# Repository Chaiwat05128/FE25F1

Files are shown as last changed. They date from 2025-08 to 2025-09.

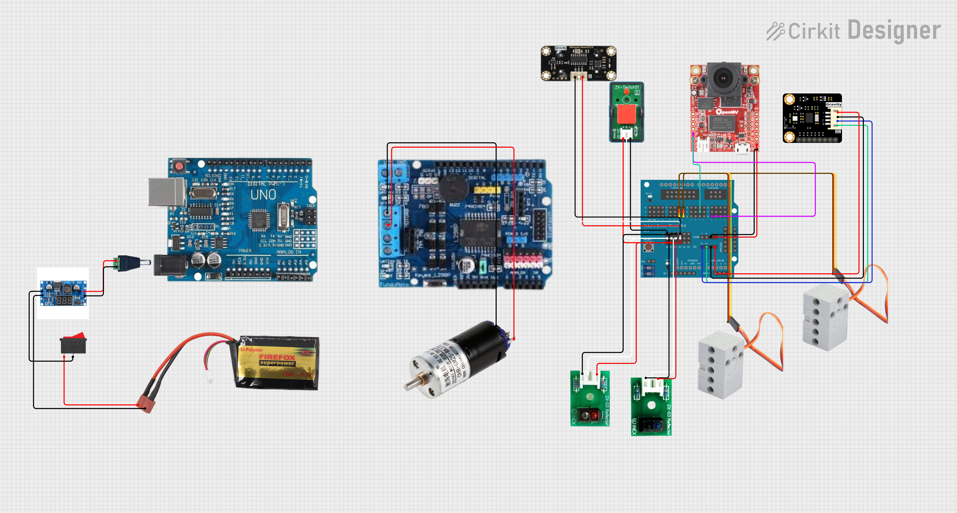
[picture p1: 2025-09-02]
Diagram/circuit_image (3).png

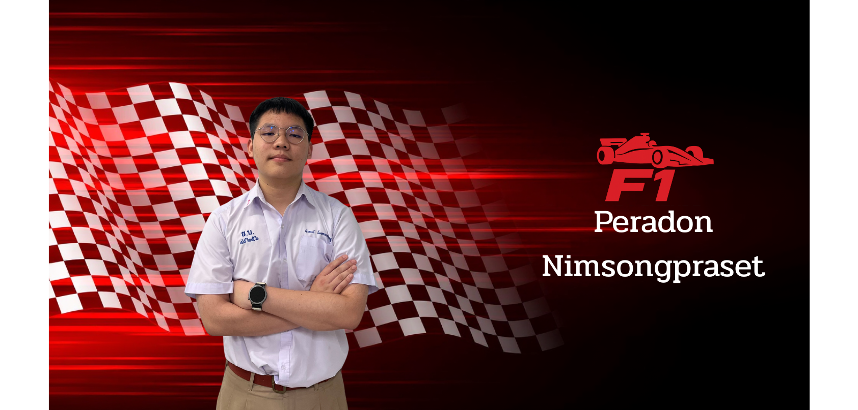
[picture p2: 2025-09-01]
Team Photo/-.zip_-_4.png

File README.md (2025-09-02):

# **🏎️Team F1 – WRO Future Engineers 2025🏁**
</p>
</p>
<br>
<p align="center">
  Team F1 logo
</p>

---

## Table of Contents
- [About Team 👥](#about-team-)
- [Project Overview 🧠](#project-overview-)
- [Timeline 🗓️](#timeline-%EF%B8%8F)
- [Robot Design](#robot-design)
  - [🖥️ Design Software](#%EF%B8%8F-design-software)
  - [🛠️ Hardware Design](#%EF%B8%8F-hardware-design)
    - [Bambu Lab X1C 3D Printer](#bambu-lab-x1c-3d-printer)
    - [Filament](#filament)
      - [ABS](#abs)
      - [PLA](#pla)
    - [Servo Bracket](#servo-bracket)
    - [Drive Bearing 1 & 2](#drive-baring-1--2)
    - [Bearing Spacer 1 & 2](#baring-spacer-1--2)
    - [Gear System](#gear)
- [Steering Mechanic Part](#steering-mechanic-part)
  - [⚙️ Geek Servo 360](#%EF%B8%8F-geek-servo-360)
- [🚗 Drive and Power Train](#-drive-and-power-train)
  - [Chihai Motor 25-370K](#chihai-motor-25-370k)
  - [LEGO Technic Differential Gear](#lego-technic-differential-gear)
  - [LEGO 8pc Technic Wheel and Tire Set](#lego-8pc-technic-wheel-and-tire-set-mindstorms-nxtev3-tyre)
  - [Lego Black Tire 49.5x20 and Light Bluish Gray Wheel](#lego-black-tire-495x20-x4-and-light-bluish-gray-wheel-304mm-x-20mm-x4)
- [Energy Management and Inspection](#energy-management-and-inspection)
  - [Gravity: URM09 Ultrasonic Distance Sensor](#gravity-urm09-ultrasonic-distance-sensor)
  - [ZX-03 Reflective Infrared Sensor Module](#zx-03-reflective-infrared-sensor-module)
  - [OpenMV Cam H7](#openmv-cam-h7)
  - [SEN 0253](#sen-0253)
- [Controller](#controller)
  - [Major Controller](#major-contoller)
    - [UNO R3](#uno-r3)
  - [Expansion Board](#expansion-board)
    - [L298P DC Motor Drive Shield](#l298p-dc-motor-drive-shield)
    - [Uno R3 Sensor Shield V5.0 for Arduino](#uno-r3-sensor-shield-v50-for-arduino)
- [Power Management](#power-managment)
  - [FIREFOX Li-Polymer BATTERY 20C 1300mAh/11.1V](#firefox-li-polymer-batterry-20c-1300mah111v)
  - [On/Off Switch](#onoff-switch--spst-onoff-switch-2-pin-rocker-switch-dc-125250v)
  - [Step-down: HW-360 V6.0](#step-down--hw-360-v60)
  - [ZX-Switch01](#zx-switch01)
- [WRO Future Engineers 2025 - Robot Components & Budget](wro-future-engineers-2025---robot-components--budget)
- [Programming](#programing)
  - [🚗 Future Engineer 2025 - Self-Driving Car Robot](#-future-engineer-2025---self-driving-car-robot)
  - [🎯 Mission Overview](#-mission-overview)
  - [🏗️ System Architecture](#%EF%B8%8F-system-architecture)
    - [Core Navigation Algorithm](#core-navigation-algorithm)
  - [🔧 Hardware Components](#-hardware-components)
    - [📋 Component List](#-component-list)
    - [⚙️ Pin Configuration](#%EF%B8%8F-pin-configuration)
  - [🎨 Line Detection Logic](#-line-detection-logic)
    - [🔴 Red Line → Turn Right](#-red-line--turn-right)
    - [🔵 Blue Line → Turn Left](#-blue-line--turn-left)
    - [🎯 Turn Execution Sequence](#-turn-execution-sequence)
  - [📐 Wall Following System](#-wall-following-system)
    - [🎛️ PID Controller Setup](#%EF%B8%8F-pid-controller-setup)
    - [📏 Distance Calculation](#-distance-calculation)
    - [🎯 Why Servo Tracks Compass Heading](#-why-servo-tracks-compass-heading)
  - [🚧 Obstacle Avoidance System](#-obstacle-avoidance-system)
    - [📷 Camera-Based Block Detection](#-camera-based-block-detection)
    - [🤝 Steering Blend Algorithm](#-steering-blend-algorithm)
  - [🎮 Control Flow States](#-control-flow-states)
    - [🔄 Robot Operation Modes](#-robot-operation-modes)
    - [🎛️ Variable Synchronization](#%EF%B8%8F-variable-synchronization)
  - [🔬 Mathematical Functions](#-mathematical-functions)
    - [🧮 Angle Wrapping](#-angle-wrapping)
    - [🎯 Motor Speed Control](#-motor-speed-control)
  - [📊 Performance Characteristics](#-performance-characteristics)
    - [⏱️ Timing Parameters](#%EF%B8%8F-timing-parameters)
    - [🎚️ Control Parameters](#%EF%B8%8F-control-parameters)
  - [🎮 User Operation](#-user-operation)
    - [🔘 Button Control Sequence](#-button-control-sequence)
    - [🔊 Audio Feedback](#-audio-feedback)
  - [🔄 Algorithm Flow Diagram](#-algorithm-flow-diagram)
  - [📷 Vision System Details](#-vision-system-details)
    - [🎯 Object Detection Criteria](#-object-detection-criteria)
    - [📊 Camera Specifications](#-camera-specifications)
  - [🧭 Compass & Navigation](#-compass--navigation)
    - [🎯 Why Ultrasonic Servo Uses Compass](#-why-ultrasonic-servo-uses-compass)
    - [🎛️ PID Control Integration](#%EF%B8%8F-pid-control-integration)
  - [🎨 Line Detection Algorithm](#-line-detection-algorithm)
    - [🟢 Sensor Reading & Color Discrimination](#-sensor-reading--color-discrimination)
    - [🔄 Turn Execution Details](#-turn-execution-details)
  - [🚧 Advanced Features](#-advanced-features)
    - [⏱️ Adaptive Timing System](#%EF%B8%8F-adaptive-timing-system)
    - [🎯 Dynamic Speed Control](#-dynamic-speed-control)
    - [🔒 Safety Features](#-safety-features)
  - [🎯 Competition Strategy](#-competition-strategy)
    - [🏁 Open Challenge Objectives](#-open-challenge-objectives)
    - [🎖️ Key Success Factors](#%EF%B8%8F-key-success-factors)
  - [🚀 Getting Started](#-getting-started)
    - [📋 Prerequisites](#-prerequisites)
    - [🔧 Setup Steps](#-setup-steps)
  - [⚡ Technical Specifications](#-technical-specifications)

#  About Team 👥
<br>
Team Picture
</p>

**Introducing Team F1 from Yothinburana School**

We are a group of students from **Yothinburana School** who share a strong passion for programming and robotics. All three of us are active members of the school’s **Robotics Club**, which has around 30 members. We each joined the club in **Grade 7 (Mathayom 1)**, driven by a love for technology and building things from scratch.

Our team is called **"F1"**, inspired by our shared enthusiasm for **Formula 1 racing**. Beyond just being fans, we dream of one day designing and building our own **self-driving vehicle** — a goal that keeps us motivated and united as a team.

<br>

# 🧑‍🤝‍🧑 Meet the Team
**1.Chaiwat Chinsupawat - Document Designer**
<p align="center">
Chaiwat Picture
</p>
Chaiwat was chosen as the Document Designer because he has strong knowledge in both hardware and software. This allows him to clearly explain how the robot is built as well as how it is programmed. He is also skilled at communication, making complex ideas simple and easy to understand for others. In addition, his creativity and attention to detail help him design documents and presentations that are professional and engaging. These abilities make him the perfect fit for the Document Designer role in Team F1.
</p>
<br>

**2.Pongpapat Putongkam - Mechanic** 
<p align="center">
Pongpapat Picture
</p>
Pongpapat was chosen as the Mechanic because he has a natural talent for building and designing structures. He is especially good at 3D design, which allows him to create accurate models before building the actual robot. He is also skilled at assembling hardware parts with precision and enjoys solving mechanical challenges. His creativity helps him design strong and reliable robot frames, while his patience and problem-solving skills allow him to fix issues quickly. These abilities make him the best person to take charge of the robot’s hardware and structural components in Team F1.
</p>
<br>

3.**Peradon Nimsongprasert - Programmer**
<p align="center">
Peradon Picture
</p>
Peradon was chosen as the Programmer because of his strong skills in coding and logical thinking. He enjoys solving complex problems and can design efficient algorithms to control the robot. His curiosity drives him to constantly learn new programming techniques, and he is quick to adapt when facing challenges. Even though he is younger than the other members, his energy and passion for technology make him a valuable part of the team. These abilities make him the perfect person to handle the robot’s software and logic in Team F1.
<br>
<br>

| Name | Role | Responsibility |
|---|---|---|
| **Chaiwat Chinsupawat**  | 📚 Document Designer | Handles documentation and presentations |
| **Pongpapat Putongkam** | 🛠️ Mechanic | Designs and assembles the robot’s hardware and structural components |
| **Peradon Nimsongprasert** | 💻 Programmer | Codes and refines the robot’s software and logic |

> 🧒 Peradon is two years younger than Chaiwat and Pongpapat but brings equal energy and skill to the team!

<br>

# 🤝 How We Work

Even though we come from different age groups, we collaborate seamlessly. Each of us brings **unique strengths** to the team, and our clearly divided roles allow us to stay focused and productive.

We believe in:
- 🔄 Continuous collaboration
- 📖 Learning from one another
- 💡 Innovating with each challenge

<br>

# 💬 Our Mission

> _"We’re not just building robots — we’re building a future."_  

Our goal is to **innovate, build**, and one day **revolutionize autonomous vehicles**. Every challenge we face is a chance to grow, both as engineers and as a team.

<br>

in another and grow as future engineers. No matter the challenge, we stay focused on our shared dream:  
**to innovate, build, and someday revolutionize how autonomous vehicles are made.**

---

# Project Overview 🧠

Our goal is clear: **Design, build, and innovate our own self-driving robot.**

We believe in:
- 🚀 Innovation through experimentation  
- 💬 Learning through teamwork  
- 🧩 Problem-solving with creativity  
- 🛠️ Applying tech to real-world challenges  

---

# Timeline 🗓️

| Phase | Month | Goal |
|---|---|---|
| 🔍 Research | July | Understand LIDAR, OpenMV, and line tracking |
| 🛠️ Prototyping | July | Assemble base robot + test sensor input |
| 🧠 Programming | August | Implement PID control and obstacle logic |
| 🧪 Testing | August | Real-world simulation and debugging |
| 🏁 Final Submission | September | Polish and submit for WRO competition |

---

# Robot Design

For the past two years, we have continuously refined our robot through participation in the WRO Future Engineers competition, advancing to the international rounds twice:
-  **WRO PANAMA 2023**  
-  **WRO TÜRKİYE 2024**  

These experiences gave us valuable insights into how to design robots that are not only competitive but also robust, precise, and adaptable. Our current robot design builds directly on the lessons learned from our previous generations, with a stronger focus on precision engineering, durability under stress, and consistent performance in dynamic environments.

---

## 🖥️ Design Software

At the beginning of this year’s design process, we experimented with five different design tools to explore their capabilities and limitations. While Blender offered a user-friendly and intuitive interface, we realized that it lacked the precision required for engineering-grade robotics. For the first time, we made the shift to a professional-grade CAD tool — Autodesk Fusion 360.

This decision was driven by the increasing complexity of our robot’s hardware. As we upgraded our electronic components, our mechanical structures also needed to achieve tighter tolerances and higher stability. Fusion 360 enables us to design with millimeter-level accuracy, which is critical for ensuring that sensors, motors, and moving parts align perfectly. Furthermore, its integrated simulation tools allow us to test stress points, weight distribution, and kinematics virtually, reducing trial-and-error during physical assembly.

By combining CAD precision with our team’s 3D design expertise, we have created a robot that not only looks refined in digital models but also translates seamlessly into a high-performance physical build.

---
## 🛠️ Hardware Design

### **Bambu Lab X1C 3D Printer**

<p align="center">
   3D Printer

We chose the Bambu Lab X1C 3D Printer because it is widely recognized and popular among students and beginners due to its ease of use. Unlike many professional 3D printers, it is not complex, making it ideal for learning and rapid prototyping. Despite its simplicity, the print quality is professional-grade, delivering highly detailed and precise results. Additionally, the printer is affordable relative to the performance it provides, offering excellent value for money compared to other printers on the market. This combination of usability, quality, and cost-effectiveness makes it a perfect choice for both educational and practical applications.

**🖨️ Product Features of Bambu Lab X1C**

- 🎨 **Multi-Color & Multi-Material Capability** – Print with different colors and materials in a single job.  
- ✅ **Proven Reliability** – Trusted by professionals worldwide.  
- 📏 **High-Quality Printing** – Achieves 7 μm Lidar resolution for exceptional detail.  
- ⚡ **High-Speed CoreXY** – Up to 20,000 mm/s² acceleration for rapid prints.  
- 🛠️ **Dual Auto Bed Leveling** – Ensures perfect first layers every time.  
- 🔄 **AMS 2 Pro Compatibility** – Works seamlessly with X1/P1 series printers for multi-material printing.
  
**X1C Tech Specs**

| Feature | Specification |
|---|---|
| **Build Volume (W×D×H)** | 256 × 256 × 256 mm³* |
| **Nozzle** | 0.4 mm Hardened Steel Included |
| **Hotend** | All-Metal |
| **Max Hot End Temperature** | 300 °C |
| **Filament Diameter** | 1.75 mm |
| **Supported Filament** | PLA, PETG, TPU, ABS, ASA, PVA, PET <br> Ideal for PA, PC, Carbon/Glass Fiber Reinforced Polymer |
| **Build Plate Surface** | Bambu Textured PEI Plate (Pre-installed, Random, Both compatible with Micro Lidar) |
| **Max Build Plate Temperature** | 110 °C@220V, 120 °C@110V |
| **Max Speed of Tool Head** | 500 mm/s |
| **Max Acceleration of Tool Head** | 20 m/s² |
| **Physical Dimensions** | **X1C:** 389 × 389 × 457 mm³ <br> Package size: 480 × 480 × 535 mm³ <br> Net weight: 14.13 kg, Gross weight: 18 kg <br> **X1C Combo:** Package size: 480 × 480 × 590 mm³ <br> Gross weight (AMS included): 22.3 kg |
| **Electrical Requirements** | 100–240 VAC, 50/60 Hz, 1000W@220V, 350W@110V |

🔗 [Learn more about the Bambu Lab X1C here](https://asia.store.bambulab.com/products/x1-carbon?from=navigation)  

---

### Filament
#### ABS
<p align="center">
ABS         

**Description**  
ABS plastic has a high thermal deformation temperature, making it suitable for outdoor and high-temperature applications.  
It combines strength, toughness, and durability, making it a common choice for engineering and prototyping.  

**Selling Points** 
- 💲 **Low cost** – affordable for large-scale use  
- 🛡️ **Sturdy and durable** – maintains shape under stress  
- 🔥 **Heat resistant** – withstands higher temperatures than PLA  
- 🧱 **High toughness** – resists cracking and breaking  
- 💥 **High impact resistance** – strong against drops or sudden force  

**Filament Properties**  
| Property | Value |
|---|---|
| **3D Printing Filament** | ABS |
| **Density** | 1.04 g/cm³ |
| **Heat Distortion Temp (0.45MPa)** | 78 °C |
| **Melt Flow Index** | 12 (220°C / 10kg) |
| **Tensile Strength** | 43 MPa |
| **Elongation at Break** | 22 % |
| **Flexural Strength** | 66 MPa |
| **Flexural Modulus** | 1177 MPa |
| **IZOD Impact Strength** | 29 kJ/m² |
| **Durability** | 8/10 |
| **Printability** | 8/10 |

**Recommended Printing Parameters**  
| Parameter | Value |
|---|---|
| **Extruder Temperature** | 230 – 270°C (Recommended: 240°C) |
| **Bed Temperature** | 95 – 110°C |
| **Fan Speed** | 0% |
| **Printing Speed** | 40 – 100 mm/s |
| **Heated Bed** | Required |
| **Recommended Build Surface** | High temperature tape, PVP solid glue |

---
#### PLA
<p align="center">
ดีไซน์ที่ยังไม่ได้ตั้งชื่อ (46)

**Description**  
PLA filament has **no pungent smell during printing**, making it safe and environmentally friendly.  
eSUN PLA is **FDA approved**, ensuring safer use for various applications.  

This filament is suitable for **conceptual models**, **rapid prototyping**, and even **metal parts casting** thanks to its reliable printability and smooth finish.  

**Selling Points**  
- ⚡ **High-speed printing** – consistent extrusion for faster jobs  
- ✨ **Smooth surface finish** – high-quality appearance with minimal post-processing  
- 🖨️ **Easy to print** – great for beginners and professionals alike  

**Recommended Applications**  
- Concept models  
- Rapid prototypes  
- Casting molds  
- General-purpose 3D prints  

**ePLA-Matte 3D Printing Filament - Parameter Information**

| Property | Value | Unit |
|---|---|---|
| **3D Printing Filament** | ePLA-Matte | - |
| **Density** | 1.329 | g/cm³ |
| **Heat Distortion Temp** | 51 | °C, 0.45MPa |
| **Melt Flow Index** | 5.8 | g/10min (190°C/2.16kg) |
| **Tensile Strength (Z)** | 14.31 | MPa |
| **Tensile Strength (XY)** | 25.976 | MPa |
| **Elongation at Break (Z)** | 2.26 | % |
| **Elongation at Break (XY)** | 7.23 | % |
| **Flexural Strength (Z)** | 21.1 | MPa |
| **Flexural Strength (XY)** | 42.6 | MPa |
| **Flexural Modulus (Z)** | 1782.62 | MPa |
| **Flexural Modulus (XY)** | 2249.05 | MPa |
| **IZOD Impact Strength (Z)** | 2.15 | kJ/m² |
| **IZOD Impact Strength (XY)** | 4.7 | kJ/m² |
| **Heated Bed** | Optional | - |
| **Recommended Build Surfaces** | Masking paper, PVP solid glue, PEI | - |

**Notes**
- Z-direction properties typically refer to layer adhesion strength (vertical/build direction)
- XY-direction properties refer to in-plane strength (horizontal/print plane)
- Heat distortion temperature measured at 0.45MPa load
- Melt flow index tested at 190°C with 2.16kg load
  
---

### Servo Bracket
<table align="center">
  <tr>
 <td align="center">
      <br>
      <a href="3D stl CAD filees/servo bracket 1.stl" target="_blank">
        🔗 View 3D model 2
      </a>
    </td>
  </tr>
</table>

<p>
The servo bracket is designed to securely hold a standard servo motor in place during robot arm operation.  
It provides stability by preventing unwanted movement or vibration, ensuring precise and consistent motion.  
The bracket also makes mounting easier by aligning with the chassis or other structural components.  

By using this bracket, the servo can deliver its full torque without stressing the mounting points,  
improving both durability and accuracy of the robot arm assembly.
</p>

---

### Drive Baring 1 & 2

<table align="center">
  <tr>
    <td align="center">
      <br>
      <a href="3D stl CAD filees/Drive Baring 1_.stl" target="_blank">
        🔗 View 3D model 1
      </a>
    </td>
    <td align="center">
      <br>
      <a href="3D stl CAD filees/Drive Baring 2.stl" target="_blank">
        🔗 View 3D model 2
      </a>
    </td>
  </tr>
</table>

<div>
  The upper part of <b>Drive Baring 1 & 2</b> is specifically designed to mount the <b>Chihai Motor 25-370K</b>, ensuring a secure and stable motor placement during operation.
  <br><br>
  The lower section is structured to house the <b>gear system</b>, including the <b>differential gear</b> and <b>bearing spacers</b>.  
  This configuration allows smooth transmission of torque from the motor to the wheels, reduces friction, and improves durability.
  <br><br>
  By separating the motor mount (upper) from the gear and bearing housing (lower), this design improves both <b>stability</b> and <b>ease of maintenance</b>.  
  It also makes it easier to replace or upgrade components without redesigning the entire drive system.
</div>

---

### Baring Spacer 1 & 2

<table align="center">
  <tr>
    <td align="center">
      <br>
      <a href="3D stl CAD filees/baring spacer 1.stl">
        🔗 View 3D model 1
      </a>
    </td>
    <td align="center">
      <br>
      <a href="3D stl CAD filees/baring spacer 2.stl">
        🔗 View 3D model 2
      </a>
    </td>
  </tr>
</table>

<div>
  <b>Baring Spacer 1 & 2</b> are precision components designed to maintain accurate spacing between bearings in the drive system.  
  They help align the shafts and gears correctly, preventing unnecessary friction and wear during operation.  
  <br><br>
  Spacer 1 is used to support the motor-side bearing, ensuring it stays in the optimal position for smooth rotation.  
  Spacer 2 is positioned near the differential gear to stabilize the assembly and reduce lateral movement.  
  <br><br>
  Using these spacers improves the overall <b>durability</b> of the drivetrain, enhances <b>torque transmission efficiency</b>, and allows for easier assembly and maintenance of the motor and gear components.  
</div>

---

### Gear

<table align="center">
  <tr>
    <td align="center">
      <br>
      <a href="3D stl CAD filees/gear 3.stl">
        🔗 View 3D model
      </a>
    </td>
    <td align="center">
      <br>
      <a href="3D stl CAD filees/gear 1.stl">
        🔗 View 3D model
      </a>
    </td>
    <td align="center">
      <br>
      <a href="3D stl CAD filees/gear 4.stl"> & <a href="3D stl CAD filees/gear 5.stl">
        🔗 View 3D model
      </a>
    </td>
  </tr>
</table>

<div>
  <b>Differential Gear System</b> consists of gears that transmit power from a single motor to both rear wheels efficiently.  
  <br><br>
  The gear attached to the motor sits on top of the drive bearing, receiving torque directly from the motor shaft.  
  An intermediate gear connects the motor gear to the differential assembly, ensuring smooth torque transmission while maintaining alignment with the bearing spacer.  
  The internal differential gears distribute torque to both rear wheels, allowing them to rotate at different speeds when cornering while keeping both powered.  
  <br><br>
  Unlike other components, the <b>gears are printed using PLA filament</b> to ensure they are strong and solid enough to handle the torque load during operation.  
  This provides <b>durability</b> and <b>reliable performance</b> while keeping the drivetrain lightweight and efficient.
</div>

---

# Steering Mechanic Part
<p align="center">


This Future Engineering mission, teams need to build a self-driving car and the steering mechanic determind its direction.
In our previous generation robot, we use the "Parallel steering" mechanism in which the wheels angle is equal on both side. With this
mechanism, we encounter alot of sliping at both front and back of the car which made it drift and lose its balance. So after our research,
we decided to use the "Akerman steering" mechanism. But there are two type of this particular mechanism; "Akerman",which is use globally in any manufactured cars and "Anti-Akerman", which is commonly use in formula series racing cars. "Akerman steering" is when a car is turning, the steering angle is different on both wheel with a tigher angle on the inside and a wider angle on the other side because while turnng the inside wheel turn at a smaller radius while the outside wheel is turning at a larger radius. This eliminate the scrubing(sliding) of the tires and made the turn more smooth. The "Anti-Akerman" on the other hand is the opposite with the outside wheel turnig at a thigher angle generate more grip which is need in a formula car, but it is more difficult to control (the down force generate by formula cars compensate these flaws).
In short, the "Akerman steering" mechanism is out best choice and will definitely improve out robot.

<table align="center">
  <tr>
    <td align="center">
      <br>
      🔗 3D Models: <br>
      <a href="3D stl CAD filees/STEERING BAR WITH SEN.stl" target="_blank">Steering Bar with Sensor</a><br>
      <a href="3D stl CAD filees/steering bar AB 1.stl" target="_blank">Steering Bar AB</a><br>
      <a href="3D stl CAD filees/steering leg LR 1.stl" target="_blank">Steering Leg LR</a><br>
      <a href="3D stl CAD filees/steering leg spacer 1.stl" target="_blank">Steering Leg Spacer</a><br>
      <a href="3D stl CAD filees/steering shaft 1.stl" target="_blank">Steering Shaft</a><br>
      <a href="3D stl CAD filees/steering spacer 1.stl" target="_blank">Steering Spacer</a>
    </td>
  </tr>
</table>

 **How We Steer the Robot?**  

We use the **Geek Servo 360**, a compact yet powerful servo motor with:  
- **360° rotation**  
- **Max torque**: 1.6 kg·cm  
- **Turning speed**: 60° in 0.14s  
- **Weight**: only 20g  
- **LEGO-compatible mount**, making it easy to attach to the robot fram
  
## **⚙️ Geek Servo 360**

<p align="center">
Greek servo 

The Geek Servo 360 is the heart of our steering system. During the design process, we needed a servo that combined LEGO compatibility, compact size, and reliable torque. After testing several options, we chose the Geek Servo 360 because it provides the ideal balance of speed, strength, and precision.

In addition to steering, we also use it to control the ultrasonic sensor, adjusting its angle based on BNO055 error calculations to ensure accurate obstacle detection and navigation..  

- 🏎️ **Designed for LEGO systems** → snaps directly into our chassis without complex mounts  
- ⚡ **Fast response (0.14s/60°)** → quick steering corrections, ideal for sharp curves on the WRO track  
- 💪 **High torque (1.6 kg·cm @ 6V)** → strong enough to turn wheels even under load  
- 🔄 **360° continuous rotation** → allows us to experiment with advanced control algorithms (like PID steering)  
- 🪶 **Lightweight (20g)** → keeps overall robot weight low for better acceleration  

Unlike regular LEGO servos, the Geek Servo 360 offers **higher precision and control flexibility**. This makes it especially useful for **Ackermann steering**, where smooth wheel angles are essential to reduce slipping and drifting.  

> **In short:** the Geek Servo 360 is the perfect match for our steering system — **LEGO-friendly, powerful, fast, and precise.**

Why We Use It:
- Compact (20g) → keeps robot light and agile
- LEGO-compatible mount → fits easily into our frame
- Strong torque (1.6 kg·cm) → reliable steering
- Fast response (0.14s per 60°) → smooth turning at speed
- 360° rotation → flexible control beyond standard 180° servos

|Power Usage | |
|---|---|
|Operating Voltage | 3.3V~|
|Rated Voltage | 4.8V|
|Rated Current | 70mA|
|Blocked Rotor Current | 900mA|
|Slipping Current | 700mA|

🔗 [View the Geek Servo 360 here](https://th.aliexpress.com/item/1005005515178664.html?gatewayAdapt=glo2tha)

---

# 🚗 Drive and Power Train

## **Chihai Motor 25-370K**

<p align="center">
  Motor12V 980RPM

The SPG20HP-20K, also well-known as the GM25 motor, is a compact DC geared motor paired with a 20:1 gearbox. It can deliver up to 225 mN·m torque with a no-load speed of 980 RPM, making it highly suitable for small-sized mobile robots, sumo robots, and other automation projects. With its standard size and availability of different gear ratios, the motor can be easily swapped without requiring modifications to the robot’s design.

The rated operating voltage of this motor is 12V. Running it at a lower voltage may result in insufficient torque to drive wheels or mechanisms effectively, while using a higher voltage can increase torque and speed but may also reduce the overall lifespan of the motor.

Before selecting this motor, our team initially used the LEGO™ Power Functions Large Motor as the main driving motor. However, during testing we encountered a major issue: when reducing the speed, the motor did not provide enough torque to reliably move the robot. This limitation made it unsuitable for our competition requirements. As a solution, we switched to the Chihai Motor 25-370K, which offers both the torque and reliability necessary to ensure stable movement and performance throughout the WRO Future Engineers 2025 challenge.

**Specification**
- High Power
- Rated Voltage: 12VDC
- Rated Current: 2.7A
- Stall Current: < 16A
- Rated Speed: 780 RPM
- No Load Speed: 980 RPM
- Rated Load Torque: 225mN.m (2.3kgf.cm)
- Gear Ratio: 20:1

**⚙️ Motor Specifications**

**Model:** CHR-GM25-BK370  
**Type:** Permanent Magnet DC Gear Motor  
**Voltage:** DC 6.0V / 12.0V  
**Max Power:** 8W (6V), 26W (12V)  
**Input Motor Speed:** 10,000 RPM (6V), 20,000 RPM (12V)  
**Max Torque:** 8.0 kg·cm (0.8 N·m)  
**Note:** Requires a **10A or higher power supply** due to high power/current.

**🔹 DC 12.0V (Max Power 26W, Input Speed 20,000 RPM)**

| Ratio | No-load Current (mA) | No-load Speed (rpm) | Rated Torque (kg·cm) | Rated Torque (N·m) | Rated Speed (rpm) | Rated Current (A) | Stall Current (A) |
|---|---|---|---|---|---|---|---|
| 1:4.4 | ≤600 | 4500 | 0.5 | 0.05 | 3500 | ≤2.7 | ≤16.0 |
| 1:10  | ≤600 | 2000 | 1.1 | 0.10 | 1580 | ≤2.7 | ≤16.0 |
| 1:20  | ≤600 | 980 | 2.3 | 0.21 | 780 | ≤2.7 | ≤16.0 |
| 1:34  | ≤600 | 580 | 3.5 | 0.34 | 460 | ≤2.7 | ≤16.0 |
| 1:45  | ≤600 | 440 | 4.5 | 0.44 | 350 | ≤2.7 | ≤16.0 |
| 1:57  | ≤600 | 440 | 6.0 | 0.59 | 275 | ≤2.7 | ≤16.0 |
| 1:75  | ≤600 | 350 | 7.0 | 0.69 | 210 | ≤2.7 | ≤16.0 |
| 1:100 | ≤600 | 260 | max 8.0 | max 0.80 | 160 | ≤2.7 | ≤16.0 |
| 1:125 | ≤600 | 160 | max 8.0 | max 0.80 | 130 | ≤2.7 | ≤16.0 |
| 1:217 | ≤600 | 90 | max 8.0 | max 0.80 | 75 | ≤2.7 | ≤16.0 |
| 1:478 | ≤600 | 40 | max 8.0 | max 0.80 | 37 | ≤2.7 | ≤16.0 |

<p><b>✔️ We use 1:20 (gearbox length 19mm)</b></p>

**Size and Details**
<p align="center">
  Size
</p>
<p align="center">
  Chihai Motor Size
</p>

🔗 [View Chihai Motor 25-370K Low Noise DC 6V / 12V / 24V Wall Climbing Car Motor WPL B-14 for Remote Control Car, DIY Smart Robot](https://www.alibaba.com/product-detail/Chihai-Motor-25-370K-Low-Noise_62197406831.html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)

---
## **LEGO Technic Differential gear** 
<p align="center">
 LEGO Differential gear

A differential gear (commonly called a differential) is a special gear system used in vehicles to allow the drive wheels to rotate at different speeds while still being powered by the same engine or motor. When combined with the Ackermann steering mechanism, it enables smoother and more efficient movement for our robot.

You might wonder, “Why LEGO?” The reason is that our school has limited facilities, which prevents us from manufacturing our own components. As a result, we rely on pre-manufactured LEGO parts. According to the regulations, teams are not allowed to use a pre-built chassis, but standard parts are permitted.

Using LEGO parts not only ensures that the differential gear works reliably, but also allows us to easily obtain multiple identical spare parts when needed.

The System includes multiple parts:
   -Technic, Gear Differential Housing : 65414
   -Technic, Gear 12 Tooth Bevel : 6589
   -Technic, Gear 28 Tooth Double Bevel with Pin Hole : 65413
   
---

## **LEGO 8pc Technic Wheel and Tire Set** (Mindstorms NXT/EV3 Tyre)**

<p align="center">
  LEGO Wheel and Tire Set

We use only two wheel in the front side
**Product Details:**
- Brand New LEGO 8pc Technic Wheel and Tire Set  
- Includes:
  - (8) LEGO Gray Wheel 30.4mm D. × 20mm without pin holes, with reinforced rim (Part No. **56145**)  
  - (8) LEGO Black Tyre 43.2 × 22 ZR (Part No. **44309**)  
- Designed for building robotic or moving LEGO creations  
- Compatible with LEGO Technic, EV3, Mindstorms, and Bionicle sets  
- Comes in a sealed clear plastic bag (no LEGO box or instructions)  

**Specifications Table:**

| Specification | Detail |
|---|---|
| Manufacturer | LEGO |
| Brand | LEGO |
| Item Weight | 2.08 oz (58.97 g) |
| Item Model Number | 11218 |
| Discontinued by Manufacturer| No |
| Manufacturer Part Number | 56145c01 |
| Rim Diameter | 0.79 in (2 cm) |
| Date First Available | June 30, 2016 |
| Size | 8 pc |
| Wheel Size | 22 mm |
| Rim Size | 0.79 in (2 cm) |
| UPC | 720066670138 |
| Package Weight | 1 lb |

🔗 [View Lego 8pc Wheel and Tire Set](https://www.ubuy.co.th/en/product/Q40EIR0-technic-lego-8pc-wheel-and-tire-set-mindstorms-nxt-ev3-tyre-56145-44309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)

---

### Lego Black Tire 49.5x20 (x4) and Light Bluish Gray Wheel 30.4mm x 20mm (x4)

<p align="center">
  LEGO Wheel and Tire Set 2

We use this two wheel in back side:</p>
**About this item**
- 100% Authentic Brand New Lego Parts
- 4x Lego 49.5mm X 20mm Rubber Tires
- 4x 30.4mm x 20mm Lego Wheels

**Technical Details**
<table border="1" cellpadding="5" cellspacing="0">
  <tr>
    <th>Attribute</th>
    <th>Details</th>
  </tr>
  <tr>
    <td>Educational Objective(s)</td>
    <td>Team Building Skills</td>
  </tr>
  <tr>
    <td>Model Number</td>
    <td>43234-735</td>
  </tr>
  <tr>
    <td>Number of Game Players</td>
    <td>1</td>
  </tr>
  <tr>
    <td>Assembly Required</td>
    <td>No</td>
  </tr>
  <tr>
    <td>Batteries Required?</td>
    <td>No</td>
  </tr>
  <tr>
    <td>Batteries Included?</td>
    <td>No</td>
  </tr>
  <tr>
    <td>Material Type(s)</td>
    <td>Rubber</td>
  </tr>
  <tr>
    <td>Colour</td>
    <td>Black, Gray</td>
  </tr>
  <tr>
    <td>Manufacturer Recommended Age</td>
    <td>4 years and up</td>
  </tr>
  <tr>
    <td>Item Model Number</td>
    <td>43234-735</td>
  </tr>
  <tr>
    <td>Package Dimensions</td>
    <td>19 x 12.6 x 4.8 cm; 68.04 g</td>
  </tr>
  <tr>
    <td>ASIN</td>
    <td>B071HFK34H</td>
  </tr>
</table>

---
# Energy management and inspection
## Gravity: URM09 Ultrasonic Distance Sensor 
<p align="center">
  LEGO Wheel and Tire Set 2

The Gravity: URM09 Ultrasonic Distance Sensor is an open dual-probe module designed with the Gravity PH2.0-3P vertical patch socket interface. It is compatible with controllers operating at both 3.3V and 5V logic levels, such as Arduino and Raspberry Pi, ensuring flexibility and ease of integration.

This sensor includes built-in temperature compensation, which significantly reduces measurement errors under extreme temperature conditions. It supports distance measurement from 2 cm to 500 cm, with 1 cm resolution and ±1% accuracy. The dual-probe design effectively minimizes the dead zone, while the onboard indicator allows convenient monitoring of the measurement process.
<p align="center">
Beam Angle</p>
In our project for WRO Future Engineers 2025, the URM09 is used to:

- Measure the distance between the robot and surrounding walls.
- Enable wall-tracking to maintain a stable path and avoid collisions.
- Detect and measure available space in parking areas, allowing the robot to park precisely and safely.

Beyond this project, the URM09 can also be applied in a wide range of scenarios, such as obstacle-avoidance robots, car reversing alarms, and smart doorbells. With its high accuracy, wide compatibility, and robust design, the URM09 plays a crucial role in ensuring efficient navigation and reliable performance in robotic systems.

**Flowchart**
<p align="center">
   สกรีนช็อต 2025-08-30 172445

**Specification**
- Power Supply: 3.3~5.5V DC
- Operating Current: 20mA
- Operating Temperature: -10℃～＋70℃
- Measurement Range: 2cm～500cm
- Resolution: 1cm
- Accuracy: 1%
- Acoustic Frequency: 38~42KHz
- Frequency: 30Hz Max
- Dimension: 47mm × 22 mm/1.85×0.87”
- Distance Formula: Distance=Vout(mV)×520/Vin(mV)</p>
🔗 [View Ultrasonic Distance Sensor](https://www.dfrobot.com/product-1832.html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)
---

## ZX-03 Reflective Infrared Sensor Module
<p align="center">
  BLUE Light Sensor
  RED Light Sensor

We use a red sensor to detect the blue line, and a blue sensor to detect the red line. The reason is that optical sensors detect objects more effectively when the emitted light wavelength is different from the color of the target surface. The contrast between the sensor light and the line color increases the reflection difference, resulting in higher accuracy and more reliable detection.
picture turn

**Description**
This module contains a TCRT5000, which integrates an infrared LED and a phototransistor in a single package. When power is supplied, the LED emits infrared light in a wide beam. If an object is placed in front of the sensor, the phototransistor receives the reflected infrared light and allows current to flow. This generates a voltage drop at the S (Vout) pin. The output voltage level depends on the intensity of the reflected infrared light received by the phototransistor — stronger reflections result in higher output voltage, while weaker reflections produce lower voltage.

The TCRT5000 Infrared Reflectance Obstacle Avoidance Line Tracking Sensor is an optical sensor that utilizes infrared (IR) light technology to detect objects and reflective surfaces. It works by emitting infrared light through an IR LED, and then measuring the amount of light reflected back to its built-in phototransistor.

Because of this simple yet effective principle, the TCRT5000 is widely used in robotics and automation projects. One of its most common applications is in line-following robots, where the sensor can distinguish between dark lines and light backgrounds by measuring differences in IR reflectivity. Additionally, it can serve as a short-range proximity sensor, making it suitable for obstacle detection, object counting, and motion tracking systems.

This sensor is popular among students, hobbyists, and engineers alike due to its low cost, compact design, and reliable performance. Its versatility and ease of integration make it an excellent choice for educational projects, competitions, and prototype development.

**TCRT5000 Infrared Reflectance Sensor**  
A compact, budget-friendly sensor that uses an IR LED and phototransistor to detect reflected infrared light.  
Perfect for **line-following robots, edge detection, proximity sensing, and Arduino DIY projects**.  

** Features**
- **Advanced IR Technology** – Detects IR reflections, like a third eye for your robot.  
- **Arduino Friendly** – Works with 3.3–5V, plug-and-play with Arduino boards.  
- **Versatile Applications** – Line tracking, edge detection, proximity sensing, object counting.  
- **Compact & Affordable** – Ideal for classrooms, competitions, and prototypes.  

**Working Principle**
- The IR LED emits light.  
- Objects in front reflect IR back to the phototransistor.  
- **Strong reflection → higher Vout**  
- **Weak reflection → lower Vout**  

**🛠 Arduino Wiring**
| Sensor Pin | Arduino Pin |
|---|---|
| VCC | 5V (or 3.3V) |
| GND | GND |
| S (Vout) | A0 |

**How to connect and use the Arduino TCRT5000 R3 tracking sensor**
<p align="center">
Wiring diagram (19)

**An example Arduino code in English for using the TCRT5000 on an Arduino UNO to detect black and white lines**

```cpp
//Example By ArduinoAll
int ledPin = 13;
int sensor = A0;
int val = 0;
void setup() {
  pinMode(ledPin, OUTPUT);
  Serial.begin(9600);
  //Serial.println("ArduinoAll TEST");
}
void loop() {
  val = analogRead(sensor);  //อ่านค่าจากเซนเซอร์
  Serial.println(val); // แสดงค่าเซนเซอร์ออกทางหน้าจอ
  if (val > 500) { // ค่า 500 สามารถกำหนดปรับได้ตามค่าแสงในห้องต่างๆ
    digitalWrite(ledPin, HIGH); // ไฟ LED ติด
  } else {
    digitalWrite(ledPin, LOW); // ไฟ LED ดับ
  }
  delay(100);
}
```

**Open the Serial Monitor to view the values detected by the TCRT5000 line-tracking sensor on the Arduino.**
<p align="center">
ดีไซน์ที่ยังไม่ได้ตั้งชื่อ (20)

Or, to get a clearer view, open the Serial Plotter
<p align="center">


</p>

🔗 [View ZX-03 Infrared Reflective Sensor](https://inex.co.th/home/product/zx-03/)

---
## OpenMV Cam H7
<p align="center">
  RED Light Sensor 
  
The OpenMV Cam is a small, low-power microcontroller board that allows developers to easily implement real-world applications using machine vision. It can be programmed using high-level Python scripts through the MicroPython Operating System, which makes handling complex outputs from machine vision algorithms and high-level data structures much simpler than traditional C/C++ programming. Despite this high-level approach, users still have full control over the OpenMV Cam’s I/O pins, enabling precise interactions with sensors, motors, and other hardware components.

Users can trigger picture or video capture based on external events, or execute machine vision algorithms to make real-time decisions for controlling I/O pins.

In our project for WRO Future Engineers 2025, the OpenMV Cam is used for color detection and parking detection:
- During the Obstacle Challenge, the camera identifies block colors. If a block is green, the robot will turn around it to the left; if the block is red, it will turn around it to the right.
- The camera is also used to detect parking areas before the robot enters, ensuring precise and safe parking.

By integrating the OpenMV Cam, our robot gains intelligent perception capabilities, allowing it to react dynamically to obstacles and navigate autonomously in complex environments.
<p align="center">
 

**Features**
- The STM32H743VI ARM Cortex M7 processor running at 480 MHz with 1MB of RAM and 2 MB of flash. All I/O pins output 3.3V and are 5V tolerant. The processor has the following I/O interfaces:
- A full-speed USB (12Mbs) interface to your computer. Your OpenMV Cam will appear as a Virtual COM Port and a USB Flash Drive when plugged in.
- A μSD Card socket capable of 100Mbs reads/writes which allows your OpenMV Cam to record video and easy pull machine vision assets off of the μSD card.
- An SPI bus that can run up to 100Mbs allowing you to easily stream image data of the system to either the LCD Shield, the WiFi Shield, or another microcontroller.
- An I2C Bus, CAN Bus, and an Asynchronous Serial Bus (TX/RX) for interfacing with other microcontrollers and sensors.
- A 12-bit ADC and a 12-bit DAC.
- Three I/O pins for servo control.
- Interrupts and PWM on all I/O pins (there are 10 I/O pins on the board).
- And, an RGB LED and two high power 850nm IR LEDs.
- A removable camera module system allowing the OpenMV Cam H7 to interface with different sensors:
- The OpenMV Cam H7 comes with an OV7725 image sensor is capable of taking 640x480 8-bit grayscale images or 640x480 16-bit RGB565 images at 60 FPS when the resolution is above 320x240 and 120 FPS when it is below. Most simple algorithms will run at above 60 FPS. Your image sensor comes - with a 2.8mm lens on a standard M12 lens mount. If you want to use more specialized lenses with your image sensor you can easily buy and attach them yourself.
- A LiPo battery connector is compatible with 3.7V LiPo batteries commonly sold online for hobbyist robotics applications.

<p align="center">
 

**Applications**
- **Frame Differencing** → detect motion for security systems  
- **Color Tracking** → track up to 16 colors for line following, target tracking, etc.  
- **Marker Tracking** → detect multi-color tags for object identification  
- **Face Detection** → Haar Cascade-based face & eye recognition  
- **Eye Tracking** → detect gaze direction to control systems  
- **Person Detection** → TensorFlow Lite model for human detection  
- **Optical Flow** → measure translation for quadcopters & stabilization  
- **QR/Barcode Recognition** → decode QR codes, DataMatrix, and 1D barcodes  
- **AprilTag Tracking** → robust fiducial marker detection (12 FPS @ 160×120)  
- **Line Detection** → infinite & segmented line recognition (ideal for robocars)  
- **Circle Detection** → simple shape detection  
- **Rectangle Detection** → quad-based detection using AprilTag library  
- **Template Matching** → locate predefined patterns/images  
- **Image Capture** → save BMP/JPG/PPM/PGM images (with overlays)  
- **Video Recording** → record MJPEG, GIF, or RAW video (with live vision overlays)  
- **TensorFlow Lite Support** → run custom ML models for classification/segmentation  

**Technical Specifications**

| Component | Specification |
|---|---|
| **Processor** | i.MX8M Quad Processor ARM |
| | 800 MHz Quad Cortex-A53 |
| | Quad-Core Score: 2500 |
| | Single-Core Score: 650 |
| | Compute & Graphics Test: 2,100 |
| **RAM System** | LPDDR4/4X, 1866MHz/Quad |
| | Capacity: 2GB to 8GB |
| | Max Speed: 14.9 GB/s |
| **Flash System** | 128GB Broadcom |
| | eMMC Controller Flash Drive |
| | CNEX8A |
| **Specialized System for Performance** | 22bit Input |
| | Resolution |
| | 24bit Output |
| **Maximum Power Consumption** | Automotive-spec PoE and wifi modules |
| | Operating: 19W |
| | Maximum: 45W |
| | Charging: 80W+ wifi 0dB and wifi modules |
| | In-Use: 80W + wifi 0dBand and wifi |
| | Sc.PoE: 45W + ultra-wifi and wifi |
| **Base PoE** | Small Graphic - Classic |
| | Features: EIA |
| | Storage: 2.5" |
| | - Best fit- MRBA vs MRBA |
| | Support: GPIO, I²C |
| | By 24Vgp: 35mm connectivity |

**Power Consumption Details**

| Operation Mode | Power Consumption |
|---|---|
| **Power Specification** | 180W to 65 kW |
| **Input: 3.3V Level** | 180W to 45 kW |
| **Input: 5V Level** | 180W to 45 kW |
| **2.0V to 6V Level** | 180W to 45 kW |

**Temperature Range**

| Parameter | Range |
|---|---|
| **Operating** | -20°C to 85°C |
| **Operating** | -40°C to 70°C |

**Additional Notes**

- The device features automotive-grade components for enhanced reliability
- Power over Ethernet (PoE) support included
- Multiple voltage level support for flexible power management
- Wide operating temperature range for various environmental conditions
- Expandable RAM configuration from 2GB to 8GB
- High-speed connectivity with GPIO and I²C support

**ECM/NTS**
*Additional specifications and compliance information available upon request*

**Dimensions**
<p align="center">
Dimension

**Pin Out**
<p align="center">
Pin
</p>

🔗 [View OpenMV Cam H7](https://openmv.io/products/openmv-cam-h7)

---
  
## SEN 0253
<p align="center">
ดีไซน์ที่ยังไม่ได้ตั้งชื่อ (34)

The Gravity: BNO055 + BMP280 10DOF AHRS is an advanced sensor module that integrates BNO055 and BMP280 on a single board, creating a compact 10 Degrees-of-Freedom (10DOF) sensor for intelligent orientation and environmental sensing.

BNO055 is a small, powerful 9-axis Absolute Orientation Sensor. It is a system-in-package that combines:
- A triaxial 14-bit accelerometer
- A triaxial 16-bit gyroscope
- A triaxial geomagnetic sensor
- A 32-bit microcontroller

At only 5.2 x 3.8 x 1.1 mm³, it is significantly smaller than comparable discrete or system-on-board solutions. BNO055 not only provides raw data from the accelerometer, gyroscope, and geomagnetic sensors, but also outputs fused data such as quaternions, Euler angles, and vectors. Its built-in MCU handles complex sensor fusion algorithms, freeing users from manual processing and enabling fast integration into projects like smartphones, wearable devices, and robotics.

BMP280 is an absolute barometric pressure sensor that measures both pressure and temperature, which can be converted to altitude using specific formulas. It uses Bosch’s proven piezoresistive pressure technology, offering high accuracy, linearity, long-term stability, and EMC robustness, making it ideal for mobile and embedded applications.

By combining these two sensors, the 10DOF AHRS module provides orientation and environmental sensing in one compact package. The standard Gravity I2C interface simplifies integration, avoiding the complications of multiple sensors from different vendors and saving time for product innovation. This module is ideal for applications such as:
- Wearable hardware
- Augmented reality and immersive gaming
- Personal health and fitness devices
- Indoor navigation and robotics

Any application requiring reliable context awareness

In our project, we previously used the ZX-IMU, but we encountered frequent drift and instability in gyroscope readings. To achieve more stable and reliable orientation data, we switched to the Gravity BNO055 + BMP280 10DOF AHRS, which ensures precise navigation and performance in the WRO Future Engineers 2025 competition.

**Can read 3-axis**</p>
<p align="center">
 

**Sample Code**
Program Function: Retrieve data from the sensor on the x, y, and z axes, and print it out via the serial port.
```cpp
/*!
  * read_data.ino
  *
  * Download this demo to test read data from bno055
  * Data will print on your serial monitor
  *
  * Product: https://www.dfrobot.com.cn/goods-1860.html
  * Copyright   [DFRobot](https://www.dfrobot.com), 2016
  * Copyright   GNU Lesser General Public License
  *
  * version  V1.0
  * date  07/03/2019
  */

#include "DFRobot_BNO055.h"
#include "Wire.h"

typedef DFRobot_BNO055_IIC    BNO;    // ******** use abbreviations instead of full names ********

BNO   bno(&Wire, 0x28);    // input TwoWire interface and IIC address

// show last sensor operate status
void printLastOperateStatus(BNO::eStatus_t eStatus)
{
  switch(eStatus) {
  case BNO::eStatusOK:   Serial.println("everything ok"); break;
  case BNO::eStatusErr:  Serial.println("unknow error"); break;
  case BNO::eStatusErrDeviceNotDetect:   Serial.println("device not detected"); break;
  case BNO::eStatusErrDeviceReadyTimeOut:    Serial.println("device ready time out"); break;
  case BNO::eStatusErrDeviceStatus:    Serial.println("device internal status error"); break;
  default: Serial.println("unknow status"); break;
  }
}

void setup()
{
  Serial.begin(115200);
  bno.reset();
  while(bno.begin() != BNO::eStatusOK) {
    Serial.println("bno begin faild");
    printLastOperateStatus(bno.lastOperateStatus);
    delay(2000);
  }
  Serial.println("bno begin success");
}

#define printAxisData(sAxis) \
  Serial.print(" x: "); \
  Serial.print(sAxis.x); \
  Serial.print(" y: "); \
  Serial.print(sAxis.y); \
  Serial.print(" z: "); \
  Serial.println(sAxis.z)

void loop()
{
  BNO::sAxisAnalog_t   sAccAnalog, sMagAnalog, sGyrAnalog, sLiaAnalog, sGrvAnalog;
  BNO::sEulAnalog_t    sEulAnalog;
  BNO::sQuaAnalog_t    sQuaAnalog;
  sAccAnalog = bno.getAxis(BNO::eAxisAcc);    // read acceleration
  sMagAnalog = bno.getAxis(BNO::eAxisMag);    // read geomagnetic
  sGyrAnalog = bno.getAxis(BNO::eAxisGyr);    // read gyroscope
  sLiaAnalog = bno.getAxis(BNO::eAxisLia);    // read linear acceleration
  sGrvAnalog = bno.getAxis(BNO::eAxisGrv);    // read gravity vector
  sEulAnalog = bno.getEul();                  // read euler angle
  sQuaAnalog = bno.getQua();                  // read quaternion
  Serial.println();
  Serial.println("======== analog data print start ========");
  Serial.print("acc analog: (unit mg)       "); printAxisData(sAccAnalog);
  Serial.print("mag analog: (unit ut)       "); printAxisData(sMagAnalog);
  Serial.print("gyr analog: (unit dps)      "); printAxisData(sGyrAnalog);
  Serial.print("lia analog: (unit mg)       "); printAxisData(sLiaAnalog);
  Serial.print("grv analog: (unit mg)       "); printAxisData(sGrvAnalog);
  Serial.print("eul analog: (unit degree)   "); Serial.print(" head: "); Serial.print(sEulAnalog.head); Serial.print(" roll: "); Serial.print(sEulAnalog.roll);  Serial.print(" pitch: "); Serial.println(sEulAnalog.pitch);
  Serial.print("qua analog: (no unit)       "); Serial.print(" w: "); Serial.print(sQuaAnalog.w); printAxisData(sQuaAnalog);
  Serial.println("========  analog data print end  ========");

  delay(1000);
}
```
**Library**
[BNO055 Library](https://github.com/DFRobot/DFRobot_BNO055)
[BMP280 Library](https://github.com/DFRobot/DFRobot_BMP280)

**Features**
BNO055:
- Outputs fused sensor data: quaternions, euler angles, rotation vector, linear acceleration, gravity, heading.
- 3 sensors in one device: 16-bit gyroscope, 14-bit accelerometer, geomagnetic sensor
- Intelligent Power Management: normal, low power and suspend mode available
BMP280：
- Barometric pressure & Temperature sensor

**Specification**
| Component | Specification |
|---|---|
| **Operating Voltage** | 3.3V ~ 5V DC |
| **Operating Current** | 5mA |
| **Interface** | Gravity-I2C |
| **BNO055 Accelerometer** | - Acceleration ranges: ±2g / ±4g / ±8g / ±16g<br>- Low-pass filter bandwidths: 1kHz ~ <8Hz<br>- Operation modes: normal, suspend, low power, standby, deep suspend<br>- On-chip interrupt control: motion-triggered interrupt |
| **BNO055 Gyroscope** | - Ranges: ±125°/s ~ ±2000°/s<br>- Low-pass filter bandwidths: 523Hz ~ 12Hz<br>- Operation modes: normal, fast power up, deep suspend, suspend, advanced power save<br>- On-chip interrupt control: motion-triggered interrupt |
| **BNO055 Geomagnetic Sensor** | - Magnetic field range: ±1300μT (x-, y-axis), ±2500μT (z-axis)<br>- Magnetic field resolution: ~0.3μT<br>- Operating modes: low power, regular, enhanced regular, high accuracy<br>- Power modes: normal, sleep, suspend, force |
| **BMP280 Digital Pressure Sensor** | - Pressure range: 300 ~ 1100 hPa<br>- Relative accuracy: ±0.12 hPa (±1 m)<br>- Absolute accuracy: ±1 hPa (±8.33 m)<br>- Temperature range: 0℃ ~ 65℃<br>- Temperature resolution: 0.01℃ |
| **Operating Temperature** | -40℃ ~ 80℃ |
| **Product Dimension** | 32 × 27 mm (1.26 × 1.06") |
<p align="center">
  

**Pin Configuration Table**

| Serial Number | Name | Functionality |
|---|---|---|
| 1 | /VCC | Positive Pole |
| 2 | -/GND | Negative Pole |
| 3 | C | I2C-SCL |
| 4 | D | I2C-SDA |
| 5 | NBOOT | Boot Mode |
| 6 | RST | Reset Pin |
| 7 | INT | Interrupt Output Pin |
| 8 | I2C_ADDR  | BNO055 I2C address Selection |
| 9 | PS2 | Protocol Selection Pin 2 |
| 10 | PS1 | Protocol Selection Pin 1 |
| 11 | BL_IND | Bootstrap Instructions |

**Protocol Selection (PS1 & PS2)**

| PS1 | PS2 | Functionality |
|-----|-----|---|
| 0 | 0 | Standard/Fast I2C Interface |
| 0 | 1 | HID OVER I2C |
| 1 | 0 | UART Interface |
| 1 | 1 | Reserved |

<p align="center">


🔗 [SEN 0253](https://wiki.dfrobot.com/Gravity_BNO055_%2B_BMP280%20intelligent_10DOF_AHRS_SKU_SEN0253)

---

# Controller

## Major Contoller
### UNO R3
<p align="center">
ดีไซน์ที่ยังไม่ได้ตั้งชื่อ (39)

The **Arduino Uno R3** is one of the most widely used and reliable microcontroller boards based on the **ATmega328P**.  
It provides a simple yet powerful platform for building embedded and robotic systems.

**Key Features ([docs.arduino.cc](https://docs.arduino.cc/hardware/uno-rev3/#features)):**
- Microcontroller: **ATmega328P (8-bit AVR)**
- Clock speed: **16 MHz**
- Digital I/O Pins: **14** (6 with PWM output)
- Analog Input Pins: **6**
- Memory: **32 KB Flash**, **2 KB SRAM**, **1 KB EEPROM**
- Power: **USB (5V)** or **External (7–12V)**
- Onboard reset button, ICSP header, and replaceable MCU chip

**Why We Chose Arduino Uno R3**

1. **Stability and Reliability**  
   The Uno R3 is known for its robust design and consistent performance, making it highly suitable for competitions where stability is crucial.

2. **Full Feature Set for Robotics**  
   With enough I/O pins, PWM support, and memory, it is capable of handling sensors, motors, and logic required in autonomous robot design.

3. **Compliance with WRO Future Engineers Rules**  
   According to the WRO Future Engineers regulations, teams must use **open-source hardware** provided through **Grammago**.  
   The Arduino Uno R3, being the most stable and well-supported open-source controller, was therefore the **best choice for our project**.

**Power Tree**
<p align="center">
สกรีนช็อต 2025-08-30 204318

**Pin Out**
<p align="center">


**Specifications**

| Feature | Specification |
|---|---|
| **Microcontroller** | ATmega328P (8-bit AVR) |
| **Operating Voltage**  | 5 V |
| **Input Voltage** | 7–12 V (recommended), 6–20 V (limits) |
| **Digital I/O Pins** | 14 (6 support PWM output) |
| **Analog Input Pins**  | 6 |
| **DC Current per I/O** | 20 mA |
| **DC Current for 3.3V**| 50 mA |
| **Flash Memory** | 32 KB (0.5 KB used by bootloader) |
| **SRAM** | 2 KB |
| **EEPROM** | 1 KB |
| **Clock Speed** | 16 MHz |
| **LED_BUILTIN** | Pin 13 |
| **USB Connection** | Type-B USB |
| **Other Interfaces** | ICSP header, power jack, reset button |
| **Dimensions** | 68.6 mm × 53.4 mm |
| **Weight** | ~25 g |

🔗 [UNO R3](https://docs.arduino.cc/hardware/uno-rev3/)

---

## Expansion Board
### L298P DC Motor Drive Shield
<p align="center">
ดีไซน์ที่ยังไม่ได้ตั้งชื่อ (40)

The **L298P Motor Driver Shield** is a dual full-bridge driver module based on the **L298P IC**.  
It is designed as an **Arduino Uno compatible shield**, making it simple to stack directly on the board without additional wiring.  
This shield allows control of **two DC motors** independently (or one stepper motor) with support for both **speed (PWM)** and **direction control**.  
It can deliver up to **2A peak per channel**, making it suitable for driving medium-sized DC motors used in robotics and automation projects.  

**Why We Use the L298P Shield**

1. **Seamless Arduino Integration**  
   Its shield format makes it directly compatible with the **Arduino Uno R3**, which is our main controller board, ensuring easy wiring and stable operation.

2. **Dual Motor Control**  
   The ability to control **two DC motors simultaneously** is essential for our robot’s differential drive system.

3. **Reliable and Proven Driver**  
   The L298P is one of the most popular and well-documented motor drivers, known for its stability in competitions and projects.

4. **WRO Future Engineers Compliance**  
   The rules allow the use of open-source shields and expansion boards. Since the L298P is fully compatible and stable, it became the best choice to power and control our driving motors during the competition.

**Product Information**
- Input voltage logic portion VD: 5 V
- The driving part of the input voltage VS: VIN Input 6 5 ~ 1 2 V, PWRIN input 4 8 ~ 2 4 V..
- The logic part of the work current I ss: ≤3 6 m A
- The driving part of the work current I o: ≤2 A
- Maximum Power Dissipation: 2 5 W (T = 7 5 ℃)
- A control signal input level: High: 2 3 V≤V in≤5 V Low: -... 0 3 V≤V in≤1 5 V
- Working temperature: - 2 5 ℃ ~ + 1 3 0 ℃
- Drive: Dual high-power H-bridge driver

**Feature**
- board with L298P motor driver chip, the direct digital IO port with the motherboard (D10 .D11. D12. D13), without cumbersome wiring.
- Onboard beeper (D4), may be provided reversing alarm ringing.
- Convenient motor interface, the motor output can be two routes.
- The two-way Bluetooth interface, can be directly inserted, no wiring.
- out of the D 2, D 3, D 5, D 6, D 7, D 9, D is not occupied by seven digital interface.
- a A 0 - A 5 six analog interface.
* forward and back lights are turned.

**Arduino test code:**
```cpp
// Arduino Test Code for L298P Motor Shield

// Motor A
int E1 = 10;   // Enable Pin for Motor A (PWM)
int M1 = 12;   // Direction Pin for Motor A

// Motor B
int E2 = 11;   // Enable Pin for Motor B (PWM)
int M2 = 13;   // Direction Pin for Motor B

void setup() {
  pinMode(M1, OUTPUT);
  pinMode(M2, OUTPUT);
}

void loop() {
  // Forward direction
  for (int value = 0; value <= 255; value += 5) {
    digitalWrite(M1, HIGH);
    digitalWrite(M2, HIGH);
    analogWrite(E1, value);  // PWM Speed for Motor A
    analogWrite(E2, value);  // PWM Speed for Motor B
    delay(30);
  }
  delay(1000);

  // Backward direction
  for (int value = 0; value <= 255; value += 5) {
    digitalWrite(M1, LOW);
    digitalWrite(M2, LOW);
    analogWrite(E1, value);  // PWM Speed for Motor A
    analogWrite(E2, value);  // PWM Speed for Motor B
    delay(30);
  }
  delay(1000);
}
```

🔗 [L298P DC Motor Drive Shield](https://www.arduitronics.com/product/2165/l298p-dc-motor-drive-shield-expansion-board)

---

### Uno R3 Sensor Shield V5.0 for Arduino
<p align="center">


**Description**
The Sensor Shield V5.0 is an expansion board designed to simplify the connection of various sensors, servos, and modules to the Arduino Uno and other compatible boards.  
It breaks out Arduino I/O pins into easy-to-use 3-pin headers (VCC, GND, Signal), making it convenient to connect multiple devices without messy wiring or soldering.  
This shield supports a wide range of modules such as ultrasonic sensors, IR sensors, servos, relays, and communication modules (Bluetooth, WiFi, etc.).  
With clearly labeled pins and dedicated ports for I²C and UART communication, the Sensor Shield V5.0 is a versatile tool for rapid prototyping and robotics projects.

**Why We Use It**
We chose the Sensor Shield V5.0 because it provides a clean, stable, and organized way to connect multiple sensors and modules to the Arduino Uno.  
For the **WRO Future Engineers 2025 competition**, wiring stability and reliability are critical during testing and competition rounds.  
This shield eliminates the risk of loose jumper wires, saves time during setup, and ensures error-free sensor integration.  
It allows us to quickly swap or test different sensors without rewiring the entire circuit, which is especially useful in competitions where adjustments are often needed.

<p align="center">


🔗 [Uno R3 Sensor Shield V5.0 for Arduino](https://www.arduitronics.com/product/107/arduino-uno-r3-sensor-shield-v5-0)

--- 

# Power Managment
## FIREFOX Li-Polymer BATTERRY 20C 1300mAh/11.1V
<p align="center">
 ดีไซน์ที่ยังไม่ได้ตั้งชื่อ (44)

**Description**
The Firefox Li-Polymer Battery (20C, 1300mAh, 11.1V) is a high-performance rechargeable Li-Po battery designed to provide stable and powerful current output for motors and robotics applications.  
With its 20C discharge rate, the battery can deliver bursts of high current, making it suitable for driving motors that require strong torque and consistent performance.  
Its compact size and lightweight build make it ideal for robotics projects where both efficiency and power-to-weight ratio are important.

**Why We Use It**
We selected the **Firefox Li-Polymer 11.1V 1300mAh** battery because it provides enough power to run the **Chihai Motor 25-370K** at full efficiency.  
During testing, we found that this battery delivers strong current without quickly discharging, ensuring longer operation time.  

In previous years, we used the **Helicox 2200mAh (7.4V / 11.1V) 30C** battery, but we faced the problem that it drained too quickly, lasting only 2–3 runs before needing replacement.  
To solve this issue, we switched to the Firefox Li-Po, which maintains more stable discharge characteristics and matches our system’s power demand better.  

This makes the Firefox battery the best balance between **power, stability, and endurance**, giving our robot reliable performance throughout the **WRO Future Engineers 2025** challenge.

| Specification | Details |
|---|---|
| **Type** | Lithium Polymer (Li-Po), 3 cells, 20C |
| **Voltage** | 11.1V |
| **Capacity** | 1200mAh |
| **Length** | 7 cm |
| **Width** | 4.2 cm |
| **Thickness** | 1.6 cm |

🔗 [FIREFOX Li-Polymer BATTERRY 20C 1300mAh/11.1V](https://shopee.co.th/%E0%B9%81%E0%B8%9A%E0%B8%95-Li-po-Firefox-20c-1300mAh-11.1v(%E0%B8%AA%E0%B8%B3%E0%B8%AB%E0%B8%A3%E0%B8%B1%E0%B8%9A%E0%B8%81%E0%B8%A5%E0%B9%88%E0%B8%AD%E0%B8%87%E0%B9%81%E0%B8%9A%E0%B8%95)-i.649460339.10883199883
)

---

## On/Off Switch : SPST ON/OFF Switch 2 Pin Rocker Switch DC 125/250V
This switch is for cutting the power from the battery to the robot. The regulation states that before starting the robot, the power must be cut off. That's when this switch came in. To use this switch we solder red wire(Positive pole) to the switch on 1 side for input. Then another solder red wire for output on the opposite side. You can put the black wire(Negative pole) straight into the step down. When the switch is turned on, the power from the battery will direct into the stepdown and then the robot. 



🔗 [On/Off Switch : SPST ON/OFF Switch 2 Pin Rocker Switch DC 125/250V](https://shopee.co.th/product/96535372/27489774822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)

---

## **Step-down** : HW-360 V6.0
This is a step-down DC-DC module. It comes with a status indicator light, a display screen that shows the voltage meter, and self-calibration of the voltage meter. The electrical voltage has an error of 0.05 V, with a measuring range of 0–40 V. We need this step down to show us how long until we need to recharge the battery.



<br><br>

**Specification**

**Input**

| Specification | Value |
|---|---|
| Input voltage | DC 4.0 ~ 38V |

**Output**

| Specification | Value |
|---|---|
| Output voltage | DC 1.25V ~ 36V continuously adjustable |
| Output current | Max 5A |
| Output power | Up to 75W |

**Measurements**

| Specification | Value |
|---|---|
| Voltmeter error | ± 0.05V |
| Measure range | 0 ~ 40V |

**Performance**

| Specification | Value |
|---|---|
| Conversion efficiency | Up to 96% |
| Load regulation | S (I) ≤ 0.8% |
| Voltage Regulation | S (u) ≤ 0.8% |

🔗 [HW-360 V6.0](https://www.googleadservices.com/pagead/aclk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)

---

## ZX-Switch01

ดีไซน์ที่ยังไม่ได้ตั้งชื่อ (63)

This button gives us an easier way to start the robot. Since the
controller board doesn't come with switches. So we found this button
that could be attached to the frame outside the board using bolt.

**Description**

When the switch is not pressed, the DATA pin is pulled up to logic “1” by resistor R2.
When the switch is pressed, the DATA pin goes to logic “0” because the switch shorts it to ground.
At the same time, current flows through the LED and resistor R1, causing the LED to light up.
In addition, the DATA pin can also function as an input, allowing the LED to be controlled (turned on or off) as desired.

🔗 [View ZX-Switch]([https://openmv.io/products/openmv-cam-h7](https://inex.co.th/home/product/zx-switch01/))

---

# WRO Future Engineers 2025 - Robot Components & Budget

## 📋 Complete Product List

### **Drive System & Motors**
| Component | Model/Type | Price (USD) | Quantity | Total (USD) | Function |
|---|---|---|---|---|---|
| Chihai Motor 25-370K | DC Geared Motor 12V, 1:20 ratio, 225mN·m torque | $15 - $25 | 1 | $15 - $25 | Main drive motor |
| LEGO Technic Differential | Housing (65414), 12T Bevel (6589), 28T Double Bevel (65413) | $30 - $50 | 1 set | $30 - $50 | Torque distribution to rear wheels |
| Geek Servo 360 | 360° rotation, 1.6 kg·cm torque, LEGO compatible | $15 - $25 | 2 | $30 - $50 | Ackermann steering control |

### **Controllers & Electronics**
| Component | Model/Type | Price (USD) | Quantity | Total (USD) | Function |
|---|---|---|---|---|---|
| Arduino Uno R3 | ATmega328P, 16MHz, 14 digital I/O pins | $25 - $35 | 1 | $25 - $35 | Main microcontroller |
| L298P Motor Driver Shield | Dual H-bridge, 2A per channel | $8 - $15 | 1 | $8 - $15 | DC motor control with PWM |
| Sensor Shield V5.0 | Arduino expansion board with 3-pin headers | $5 - $10 | 1 | $5 - $10 | Sensor connection hub |

### **Sensors & Detection**
| Component | Model/Type | Price (USD) | Quantity | Total (USD) | Function |
|---|---|---|---|---|---|
| OpenMV Cam H7 | STM32H743VI ARM Cortex M7, machine vision | $85 - $120 | 1 | $85 - $120 | Color detection, parking recognition |
| Gravity URM09 | Ultrasonic sensor, 2-500cm range, temperature compensation | $12 - $18 | 1 | $12 - $18 | Wall tracking, distance measurement |
| ZX-03 IR Sensors | TCRT5000 reflective sensors (red & blue versions) | $3 - $5 | 2 | $6 - $10 | Line following detection |
| SEN0253 (BNO055+BMP280) | 10DOF AHRS with gyro, accel, magnetometer | $35 - $50 | 1 | $35 - $50 | Stable orientation sensing |
| ZX-Switch01 | Push button with LED indicator | $2 - $4 | 1 | $2 - $4 | Robot start button |

### **Power Management**
| Component | Model/Type | Price (USD) | Quantity | Total (USD) | Function |
|---|---|---|---|---|---|
| Firefox Li-Polymer Battery | 11.1V, 1300mAh, 20C discharge rate | $25 - $40 | 1 | $25 - $40 | Main power source |
| SPST Rocker Switch | ON/OFF switch, 2-pin, DC 125/250V | $2 - $5 | 1 | $2 - $5 | Power cutoff (regulation compliance) |
| HW-360 V6.0 Step-down | DC-DC converter with voltage display, 4-38V input | $8 - $12 | 1 | $8 - $12 | Voltage regulation & monitoring |

### **Wheels & Mechanical**
| Component | Model/Type | Price (USD) | Quantity | Total (USD) | Usage |
|---|---|---|---|---|---|
| LEGO Wheel Set (30.4mm) | Gray wheels + black tires (43.2×22) | $25 - $35 | 1 set | $25 - $35 | Front steering wheels |
| LEGO Wheel Set (49.5×20) | Light gray wheels + black tires | $30 - $40 | 1 set | $30 - $40 | Rear drive wheels |

### **3D Printed Parts** *(Material Cost Only)*
| Component | Material | Estimated Cost (USD) | Function |
|---|---|---|---|
| Servo Bracket | ABS | $2 - $3 | Secure servo mounting |
| Drive Bearing 1 & 2 | ABS | $5 - $8 | Motor housing & gear system |
| Bearing Spacer 1 & 2 | ABS | $1 - $2 | Precise bearing alignment |
| Steering Components | ABS | $3 - $5 | Ackermann steering mechanism |
| Custom Gears | PLA | $2 - $4 | Torque transmission system |

---

## 💰 **Budget Summary**

### **Component Categories**
```
Drive System & Motors:      $60 - $100
Controllers & Electronics:  $38 - $60  
Sensors & Detection:        $140 - $202
Power Management:           $35 - $57
Wheels & Mechanical:        $55 - $75
3D Printing Materials:      $13 - $22
```

### **Total Project Cost**
```
ROBOT COMPONENTS TOTAL: $356 - $541 USD
```

---

# Programing

This project implements a multi-functional robot capable of **line following**, **wall tracking**, **compass-based steering**, **obstacle avoidance**, and **motor control** using Arduino, sensors, and OpenMV camera.

---
# 🚗 Future Engineer 2025 - Self-Driving Car Robot

> **Open Challenge Round**: Autonomous robot car navigation with line detection and wall following





## 🎯 Mission Overview

This autonomous robot car is designed for the **Future Engineer 2025 Open Challenge**. The robot navigates a track by:
- **Line Detection**: Red lines trigger right turns, blue lines trigger left turns
- **Wall Following**: Maintains optimal distance from track boundaries
- **Obstacle Avoidance**: Uses camera vision to detect and avoid blocks
- **Compass Navigation**: Precise heading control with PID steering

---

## 🏗️ System Architecture

### Core Navigation Algorithm
```cpp
void loop() {
    camera.handleIncomingData();    // 📷 Process camera data
    getBNO();                       // 🧭 Read compass heading
    line_detection();               // 🎨 Check for colored lines
    
    int distance_wall = getDistance();  // 📏 Measure wall distance
    
    // 🎛️ Calculate steering using PID controller
    int steering_degree = (1 * x) * compassPID.Run(
        (x * pvYaw) + ((distance_wall - Y)) * 
        ((float(Blocks_TURN == 'TURN') - 0.5) * 2)
    ) * -1;
    
    // 🚧 Apply obstacle avoidance if blocks detected
    int final_degree = blend_steering_with_avoidance();
    
    // 🎮 Execute movement commands
    ultra_servo(-pvYaw, Blocks_TURN);  // Rotate sensor to track wall
    motor_and_steer(final_degree);     // Apply steering and speed
}
```

---

## 🔧 Hardware Components

### 📋 Component List
| Component | Pin | Purpose |
|---|-----|---|
| **BNO055 IMU** | I2C | 🧭 Compass heading & orientation |
| **OpenMV Camera** | Pin 3 (RX) | 📷 Object detection & avoidance |
| **Motor Driver** | 11,12,13 | ⚡ Speed & direction control |
| **Steering Servo** | Pin 9 | 🎯 Car direction control |
| **Ultrasonic Servo** | Pin 8 | 📐 Sensor rotation for wall tracking |
| **Distance Sensor** | Pin A3 | 📏 Wall distance measurement |
| **Red Line Sensor** | Pin A1 | 🔴 Red line detection |
| **Green Line Sensor** | Pin A2 | 🟢 Blue line detection |
| **Start Button** | Pin A0 | 🔘 Manual start/stop control |
| **Buzzer** | Pin 4 | 🔊 Audio feedback |

### ⚙️ Pin Configuration
```cpp
// Motor Control
#define ENA 11    // Motor speed control (PWM)
#define IN1 12    // Motor direction pin 1
#define IN2 13    // Motor direction pin 2

// Servo Controls
#define STEER_SRV 9    // Steering servo
#define ULTRA_SRV 8    // Ultrasonic sensor servo

// Sensors
#define ULTRA_PIN A3   // Ultrasonic distance sensor
#define RED_SEN A1     // Red line detection
#define GEEN_SEN A2    // Green/Blue line detection
#define BUTTON A0      // Start/stop button
#define buzzerPin 4    // Audio feedback buzzer

// Communication
#define RX_PIN 3       // Camera data input (OpenMV)
#define TX_PIN 5       // Camera data output
```

---

## 🎨 Line Detection Logic

### 🔴 Red Line → Turn Right
```cpp
if (lowest_red_reading > 400) {
    // Red line detected first
    TURN = 'L';           // Set turn mode to left wall following
    Blocks_TURN = 'L';    // Synchronize block avoidance
    x = -1;               // Set direction multiplier
    Y = 26;               // Adjust target wall distance
    compass_offset -= 90; // Rotate compass reference 90° CCW
}
```

### 🔵 Blue Line → Turn Left  
```cpp
else {
    // Blue line detected first
    TURN = 'R';           // Set turn mode to right wall following
    Blocks_TURN = 'R';    // Synchronize block avoidance  
    x = 1;                // Set direction multiplier
    Y = 26;               // Adjust target wall distance
    compass_offset += 90; // Rotate compass reference 90° CW
}
```

### 🎯 Turn Execution Sequence
1. **🔊 Audio Alert**: Buzzer confirms line detection
2. **🎨 Color Analysis**: Determine red vs blue line
3. **🧭 Compass Update**: Adjust heading reference by ±90°
4. **🚗 Direction Change**: Execute turn using compass feedback
5. **📏 Resume Tracking**: Continue wall following in new direction

---

## 📐 Wall Following System

### 🎛️ PID Controller Setup
```cpp
PID_v2 compassPID(0.6, 0.0001, 0.02, PID::Direct);

void setup() {
    compassPID.Start(0, 0, 0);
    compassPID.SetOutputLimits(-180, 180);  // Steering angle limits
    compassPID.SetSampleTime(10);           // 10ms update rate
}
```

### 📏 Distance Calculation
```cpp
float getDistance() {
    // Convert analog reading to distance (0-50cm range)
    return min(mapf(analogRead(ULTRA_PIN), 0, 1023, 0, 500), 50);
}
```

### 🎯 Why Servo Tracks Compass Heading
The ultrasonic servo rotates based on the robot's compass heading to ensure it always points toward the wall being followed:

```cpp
void ultra_servo(int degree, char mode_steer) {
    int middle_degree = 0;
    if (mode_steer == 'F') middle_degree = 270;      // Forward scan
    else if (mode_steer == 'R') middle_degree = 360; // Right wall tracking
    else if (mode_steer == 'L') middle_degree = 180; // Left wall tracking
    
    // Apply compass correction to maintain wall tracking
    Servo_Value = ((max(min(middle_degree + degree, 360), 180)) / 2);
    myservo1.write(Servo_Value);
}
```

**🔄 Tracking Logic**: When the robot turns, the compass heading changes, so the ultrasonic servo must rotate accordingly to continue pointing at the wall for accurate distance measurements.

[First Round clip](https://youtu.be/TkWOwLYxJJ0)

---

## 🚧 Obstacle Avoidance System

### 📷 Camera-Based Block Detection
```cpp
float calculate_avoidance() {
    if (camera.isBlockFound()) {
        BlobData currentBlob = camera.getBlobData();
        
        // 📏 Check object dimensions (height > 1.33 × width = likely a block)
        if (currentBlob.height > 1.33 * float(currentBlob.width)) {
            found_block = true;
            
            // 📐 Calculate block position using camera geometry
            float distance = (targetHeight * focalLength * 100) / objectHeight;
            float detected_degree = deltaX * 40 / frameWidth;
            
            float blockPositionX = distance * sin(degreesToRadians(detected_degree));
            float blockPositionY = distance * cos(degreesToRadians(detected_degree)) - 17;
            
            // 🎯 Determine avoidance direction
            if (signature == 1) {
                // Avoid to the right
                avoidance_degree = min(radiansToDegree(atan2(blockPositionX + 9, blockPositionY)), -5);
                Blocks_TURN = 'R';
            } else {
                // Avoid to the left  
                avoidance_degree = max(radiansToDegree(atan2(blockPositionX - 9, blockPositionY)), 5);
                Blocks_TURN = 'L';
            }
        }
    }
    return avoidance_degree;
}
```

### 🤝 Steering Blend Algorithm
```cpp
// Combine normal steering with obstacle avoidance
int final_degree = map(
    max(found_block, found_block_factor), 0, 1,
    steering_degree,  // Normal wall-following steering
    mapf(min(max(distance_wall, 5), 40), 5, 40, steering_degree, avoidance_degree * 2.5)
);
```

---

## 🎮 Control Flow States

### 🔄 Robot Operation Modes

| State | Description | Behavior |
|---|---|---|
| `TURN = 'U'` | 🎯 **Initial/Undefined** | Ready to detect first line and set direction |
| `TURN = 'L'` | ↩️ **Left Turn Mode** | Follows left wall, turns left at intersections |
| `TURN = 'R'` | ↪️ **Right Turn Mode** | Follows right wall, turns right at intersections |
| `found_block = true` | 🚧 **Avoidance Mode** | Temporary obstacle avoidance steering |

### 🎛️ Variable Synchronization
```cpp
// Key variables that work together:
char TURN = 'U';          // Overall robot direction mode
char Blocks_TURN = 'U';   // Block avoidance direction (synchronized with TURN)
int x = -1;               // Direction multiplier (-1 for left, +1 for right)
int Y = 30;               // Target wall distance in cm
float avoidance_degree;   // Calculated obstacle avoidance angle
```

---

## 🔬 Mathematical Functions

### 🧮 Angle Wrapping
```cpp
float wrap_value(float value, float min_value, float max_value) {
    float range_val = max_value - min_value;
    while (value < min_value) value += range_val;
    while (value > max_value) value -= range_val;
    return value;  // Keeps angles within -180° to +180°
}
```

### 🎯 Motor Speed Control
```cpp
void setMotorPercent(int sp) {
    sp = constrain(sp, -100, 100);  // Limit to ±100%
    
    if (sp > 0) {        // Forward
        digitalWrite(IN1, HIGH);
        digitalWrite(IN2, LOW);
        analogWrite(ENA, map(sp, 0, 100, 0, 255));
    } else if (sp < 0) { // Backward
        digitalWrite(IN1, LOW);
        digitalWrite(IN2, HIGH);
        analogWrite(ENA, map(-sp, 0, 100, 0, 255));
    } else {             // Stop/Brake
        digitalWrite(IN1, LOW);
        digitalWrite(IN2, LOW);
        analogWrite(ENA, 0);
    }
}
```

---

## 📊 Performance Characteristics

### ⏱️ Timing Parameters
- **PID Update Rate**: 10ms for smooth control
- **Avoidance Calculation**: 50ms for responsive obstacle detection  
- **Turn Duration**: 2-4 seconds depending on maneuver complexity
- **Line Detection Timeout**: 1000ms between line detections

### 🎚️ Control Parameters
```cpp
// PID Tuning
PID_v2 compassPID(0.6, 0.0001, 0.02, PID::Direct);
//                ^^^   ^^^^^^  ^^^^
//                Kp    Ki      Kd

// Speed Control
setMotorPercent(map(abs(degree), 0, 45, 50, 60));  // 50-60% speed range

// Steering Limits  
degree = min(max(degree, -40), 40);  // ±40° maximum steering angle
```

---

## 🎮 User Operation

### 🔘 Button Control Sequence
1. **Press Button Once**: 🧭 Calibrate compass and initialize sensors
2. **Release & Press Again**: 🚀 Start autonomous navigation
3. **Hold Button**: 🛑 Emergency stop during operation

### 🔊 Audio Feedback
```cpp
void simpleBeep() {
    digitalWrite(buzzerPin, HIGH);
    delay(100);
    digitalWrite(buzzerPin, LOW);
}
```
- **Single Beep**: System ready or line detected
- **Continuous Beeping**: Sensor initialization error

---

## 🔄 Algorithm Flow Diagram

```
START
  ↓
🔧 Initialize Hardware & Calibrate Compass
  ↓
⏸️ Wait for Button Press
  ↓
┌─────────────────────────────────────┐
│          🔄 MAIN LOOP              │
├─────────────────────────────────────┤
│ 1. 📷 Read Camera Data              │
│ 2. 🧭 Update Compass Heading        │
│ 3. 🎨 Check Line Sensors            │
│    ├─ 🔴 Red Line → Turn Right      │
│    └─ 🔵 Blue Line → Turn Left      │
│ 4. 📏 Measure Wall Distance         │
│ 5. 🎛️ Calculate Steering Angle      │
│ 6. 🚧 Apply Obstacle Avoidance      │
│ 7. 🎮 Execute Motor & Servo Commands │
└─────────────────────────────────────┘
  ↓
🏁 Continue Until Lap Complete
```

---

## 📷 Vision System Details

### 🎯 Object Detection Criteria
```cpp
// Block detection algorithm
if (currentBlob.height > 1.33 * float(currentBlob.width)) {
    found_block = true;  // Object is tall enough to be a block
    
    // 📐 Calculate distance using camera focal length
    float distance = (targetHeight * focalLength * 100) / objectHeight;
    
    // 🎯 Determine avoidance direction
    if (signature == 1) {
        avoidance_degree = min(radiansToDegree(atan2(blockPositionX + 9, blockPositionY)), -5);
        Blocks_TURN = 'R';  // Avoid right
    } else {
        avoidance_degree = max(radiansToDegree(atan2(blockPositionX - 9, blockPositionY)), 5);
        Blocks_TURN = 'L';  // Avoid left
    }
}
```

### 📊 Camera Specifications
- **Frame Size**: 320×150 pixels
- **FOV**: 70° field of view
- **Communication**: 19200 baud serial
- **Detection Range**: Objects 5-40cm distance

---

## 🧭 Compass & Navigation

### 🎯 Why Ultrasonic Servo Uses Compass
The ultrasonic servo **must rotate with the robot's heading** because:

```cpp
void ultra_servo(int degree, char mode_steer) {
    int middle_degree = 0;
    if (mode_steer == 'R') middle_degree = 360; // 👉 Right wall tracking
    else if (mode_steer == 'L') middle_degree = 180; // 👈 Left wall tracking
    
    // 🧭 Apply compass correction to maintain wall tracking
    Servo_Value = ((max(min(middle_degree + degree, 360), 180)) / 2);
    myservo1.write(Servo_Value);
}
```

**🔄 Tracking Logic**: When the robot turns, its body rotates but the wall position remains fixed. The servo must counter-rotate to keep pointing at the wall for consistent distance measurements.

### 🎛️ PID Control Integration
```cpp
// Compass-based steering calculation
int steering_degree = (1 * x) * compassPID.Run(
    (x * pvYaw) +                           // Current heading error
    ((distance_wall - Y)) *                 // Wall distance error  
    ((float(Blocks_TURN == 'TURN') - 0.5) * 2)  // Turn direction factor
) * -1;
```

---

## 🎨 Line Detection Algorithm

### 🟢 Sensor Reading & Color Discrimination
```cpp
void line_detection() {
    int GEEN_value = analogRead(GEEN_SEN);  // Green sensor reading
    int red_value = analogRead(RED_SEN);    // Red sensor reading
    
    if (GEEN_value < 400 || red_value < 400) {  // Line detected threshold
        simpleBeep();  // 🔊 Audio confirmation
        
        // 🎨 Determine line color by comparing sensor values
        int lowest_red_sen = red_value;
        long timer_line = millis();
        
        // Sample red sensor for 100ms to get stable reading
        while (millis() - timer_line < 100) {
            int red_value = analogRead(RED_SEN);
            if (red_value < lowest_red_sen) {
                lowest_red_sen = red_value;
            }
        }
        
        if (lowest_red_sen > 400) {
            // 🔴 RED LINE DETECTED → TURN RIGHT
            executeLeftTurn();   // Robot turns left to follow right wall
        } else {
            // 🔵 BLUE LINE DETECTED → TURN LEFT  
            executeRightTurn();  // Robot turns right to follow left wall
        }
    }
}
```

### 🔄 Turn Execution Details
```cpp
// Turn sequence with compass feedback
while (millis() - timer_line < 2000) {
    getBNO();                    // 🧭 Update compass reading
    steering_servo(-pvYaw);      // 🎯 Counter-steer to maintain heading
    setMotorPercent(-70);        // ⚡ Reverse motor for tight turn
}
```

---

## 🚧 Advanced Features

### ⏱️ Adaptive Timing System
```cpp
found_block_factor = min(max(mapf(millis() - timer_block_decay, 0, 1000, 1, 0), 0), 1);
```
- Gradually reduces obstacle avoidance influence over time
- Prevents robot from getting "stuck" in avoidance mode
- Smooth transition back to normal wall following

### 🎯 Dynamic Speed Control
```cpp
void motor_and_steer(int degree) {
    degree = min(max(degree, -40), 40);  // Limit steering angle
    steering_servo(degree);
    
    // 🏎️ Slower speed for sharp turns, faster for straight driving
    setMotorPercent(map(abs(degree), 0, 45, 50, 60));
}
```

### 🔒 Safety Features
- **Emergency Stop**: Button hold detection
- **Sensor Validation**: Range checking and error handling  
- **Compass Calibration**: Automatic heading reference setup
- **Turn Completion**: Lap counter prevents infinite running

---

## 🎯 Competition Strategy

### 🏁 Open Challenge Objectives
- ✅ **Autonomous Navigation**: No remote control allowed
- ✅ **Line Recognition**: React correctly to red/blue turn indicators  
- ✅ **Wall Following**: Maintain consistent track positioning
- ✅ **Obstacle Avoidance**: Navigate around randomly placed blocks
- ✅ **Lap Completion**: Complete 3 laps successfully

### 🎖️ Key Success Factors
1. **🎯 Precise Calibration**: Compass zeroing and sensor thresholds
2. **⚖️ Balanced Control**: PID tuning for stable yet responsive steering  
3. **🔄 State Management**: Proper synchronization of turn modes and variables
4. **📷 Robust Vision**: Reliable block detection and distance estimation
5. **🛡️ Error Recovery**: Timeout mechanisms and fail-safe behaviors

---

## 🚀 Getting Started

### 📋 Prerequisites
```cpp
#include "Mapf.h"
#include "Servo.h" 
#include <Adafruit_Sensor.h>
#include <Adafruit_BNO055.h>
#include "CameraHandler.h"
#include <PID_v2.h>
#include <NeoSWSerial.h>
```

### 🔧 Setup Steps
1. **🔌 Wire Hardware**: Connect all components according to pin configuration
2. **📚 Install Libraries**: Ensure all required libraries are installed
3. **🧭 Calibrate Compass**: Place robot on level surface for IMU calibration  
4. **📷 Configure Camera**: Set up OpenMV camera for blob detection
5. **🎯 Test Sensors**: Verify all sensor readings are within expected ranges
6. **▶️ Upload & Run**: Upload code and press button to start

---

## ⚡ Technical Specifications

| Parameter | Value | Description |
|---|---|---|
| **Control Loop Rate** | 🔄 ~100Hz | Main loop execution frequency |
| **PID Sample Time** | ⏱️ 10ms | Compass control update rate |
| **Avoidance Update** | 📷 50ms | Camera processing interval |  
| **Turn Timeout** | ⏳ 2-4s | Maximum time for turn execution |
| **Max Steering Angle** | 🎯 ±40° | Servo steering limit |
| **Speed Range** | 🏎️ 50-60% | Motor speed based on turn angle |
| **Wall Target Distance** | 📏 30cm | Optimal wall following distance |
| **Line Detection Threshold** | 🎨 <400 | Analog sensor trigger level |

---

## 🏆 Future Engineer 2025 Ready!

This autonomous driving system implements all the core requirements for the **Future Engineer Open Challenge**:
- ✅ Bidirectional navigation capability  
- ✅ Color-based turn decision making
- ✅ Precise wall following with ultrasonic feedback
- ✅ Intelligent obstacle avoidance using computer vision
- ✅ Robust compass-based heading control
- ✅ Fail-safe mechanisms and user controls

**🚗💨 Ready to race and navigate autonomously! 🏁**

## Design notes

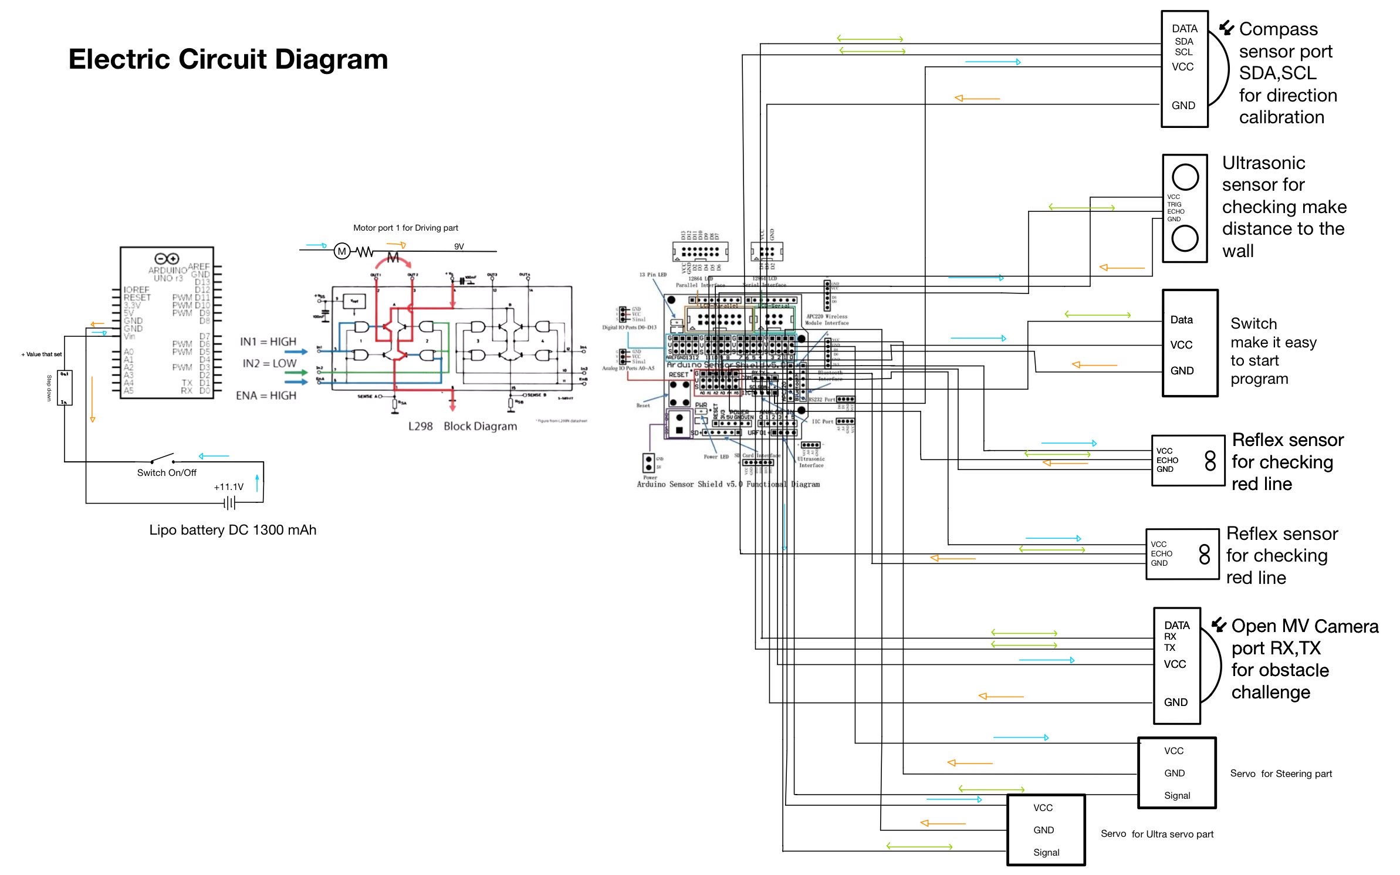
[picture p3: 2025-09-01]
Diagram/Circuit Diagram.jpg

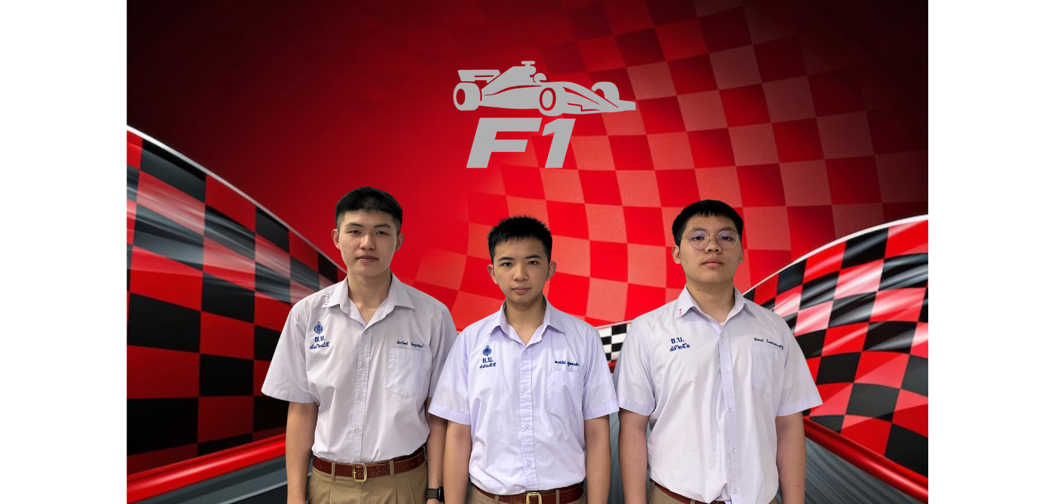
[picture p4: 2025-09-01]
Team Photo/-.zip_-_1.png

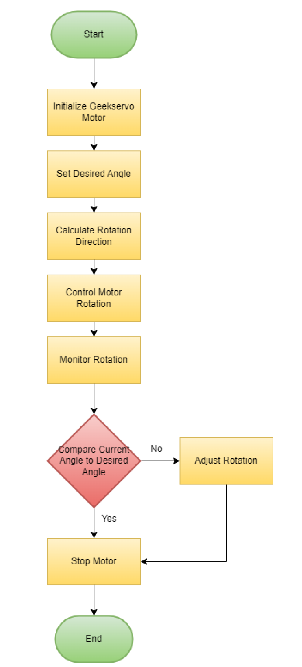
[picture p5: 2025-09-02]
Diagram/Flow chart 1.png

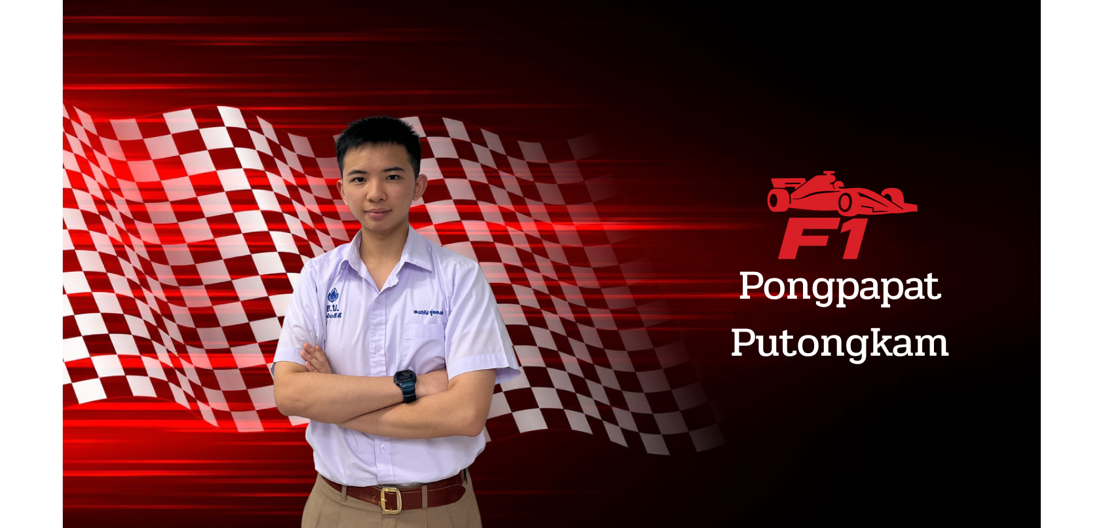
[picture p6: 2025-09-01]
Team Photo/-.zip_-_2.png

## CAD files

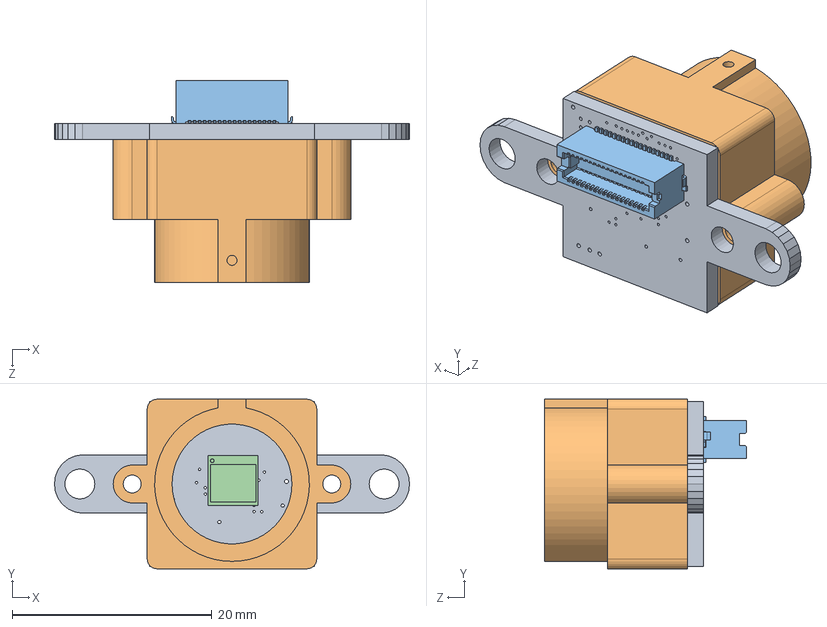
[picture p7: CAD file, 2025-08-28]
Open MV H7 model/openmv4_ov7725.SLDASM
35.6 x 17.0 x 20.2 mm
ov7725
mount_lens
DF1236
CSP2-28

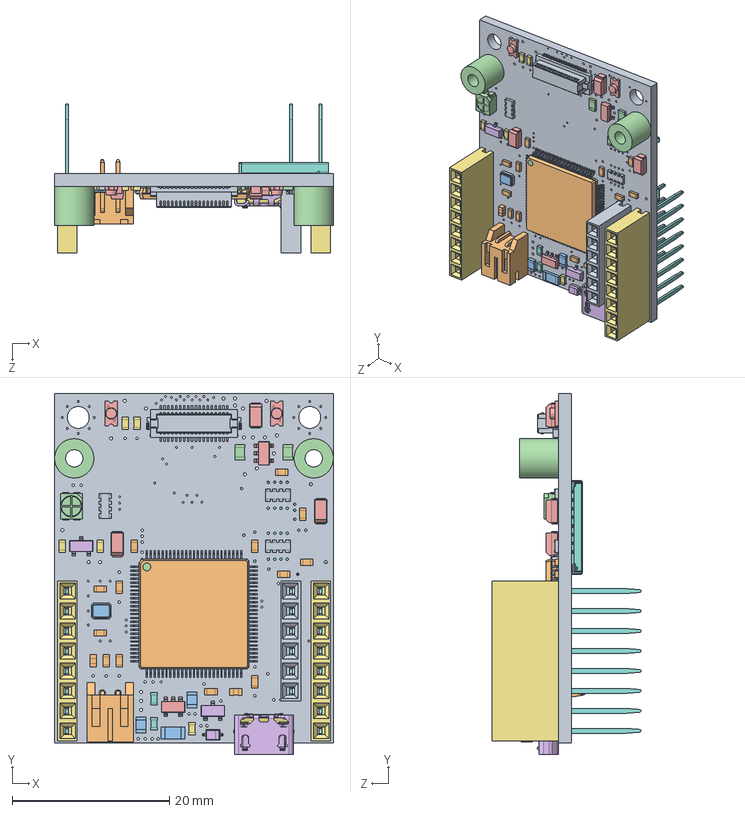
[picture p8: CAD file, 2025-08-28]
Open MV H7 model/openmv4_h7_base.SLDASM
35.6 x 45.9 x 19.0 mm
base
C0603K_C0603K x 13
C0805K_C0805K x 2
cap3216h160 x 3
SOD323_BAT54HT1G
960240-6202-AR Body8 x 2
960240-6202-AR Pin Long x 22
960240-6202-AR Body6
Capacitor 0603 x 2
LED SMD RGB
LED 1206 IR x 2
SOT 23 x 2
Resistor 0603 x 5
R0603_SJR x 2
EXBV8V x 3
User Library-LQFP100-3_case
User Library-LQFP100-3_pin x 100
User Library-LQFP100-3_circle
SOT 23-5 x 2
UJ2-MIBH2-4-SMT_01
UJ2-MIBH2-4-SMT_02
1040310811_USD1040310811
DF12-36DS-0.5V
S2B-PH-K-S(LF)(SN)
Crystal-SM2520-4
Standoff metal 5x2.5mm x 2

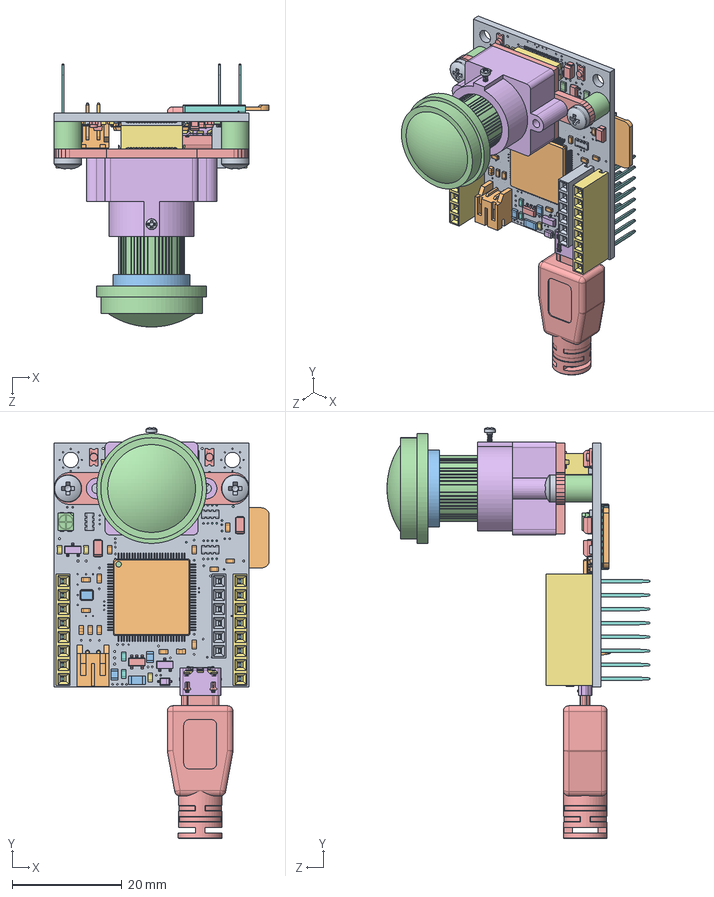
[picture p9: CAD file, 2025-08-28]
Open MV H7 model/openmv4_h7.SLDASM
39.2 x 74.9 x 47.9 mm
base
C0603K_C0603K x 13
C0805K_C0805K x 2
cap3216h160 x 3
SOD323_BAT54HT1G
960240-6202-AR Body8 x 2
960240-6202-AR Pin Long x 22
960240-6202-AR Body6
Capacitor 0603 x 2
LED SMD RGB
LED 1206 IR x 2
SOT 23 x 2
Resistor 0603 x 5
R0603_SJR x 2
EXBV8V x 3
User Library-LQFP100-3_case
User Library-LQFP100-3_pin x 100
User Library-LQFP100-3_circle
SOT 23-5 x 2
UJ2-MIBH2-4-SMT_01
UJ2-MIBH2-4-SMT_02
1040310811_USD1040310811
DF12-36DS-0.5V
S2B-PH-K-S(LF)(SN)
Crystal-SM2520-4
Standoff metal 5x2.5mm x 2
ov7725
mount_lens
DF1236
CSP2-28
pan head cross recess screw_iso x 3
microsd card
LENS_Standard
LENS_Wide
Micro USB connector

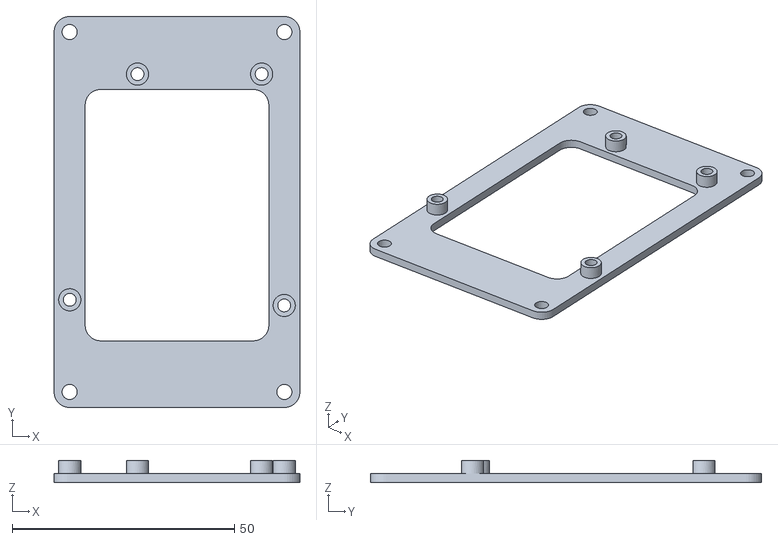
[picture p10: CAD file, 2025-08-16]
3D stl CAD filees/FE-F1 v35.stl
55.3 x 88.0 x 5.00

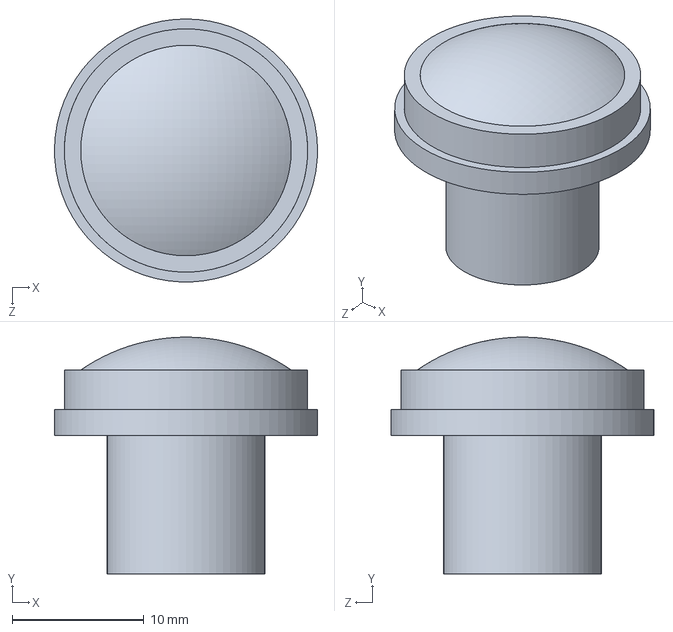
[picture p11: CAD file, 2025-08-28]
Open MV H7 model/LENS_Wide.SLDPRT
20.0 x 18.0 x 20.0 mm

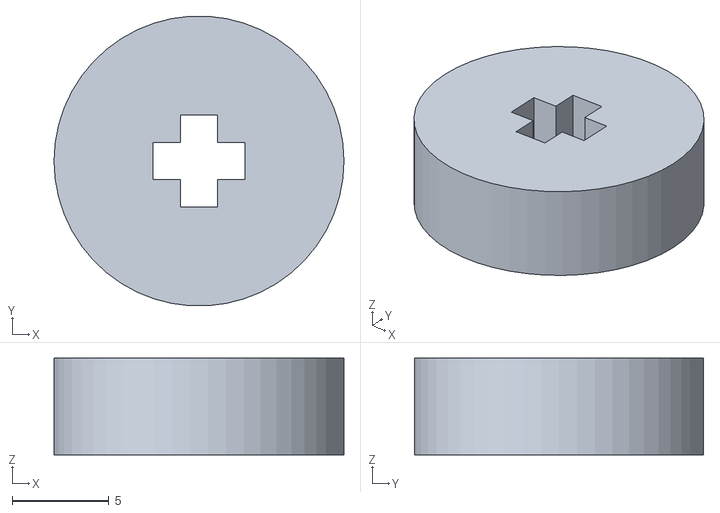
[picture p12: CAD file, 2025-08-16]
3D stl CAD filees/Norm spacer.stl
15.0 x 15.0 x 5.00

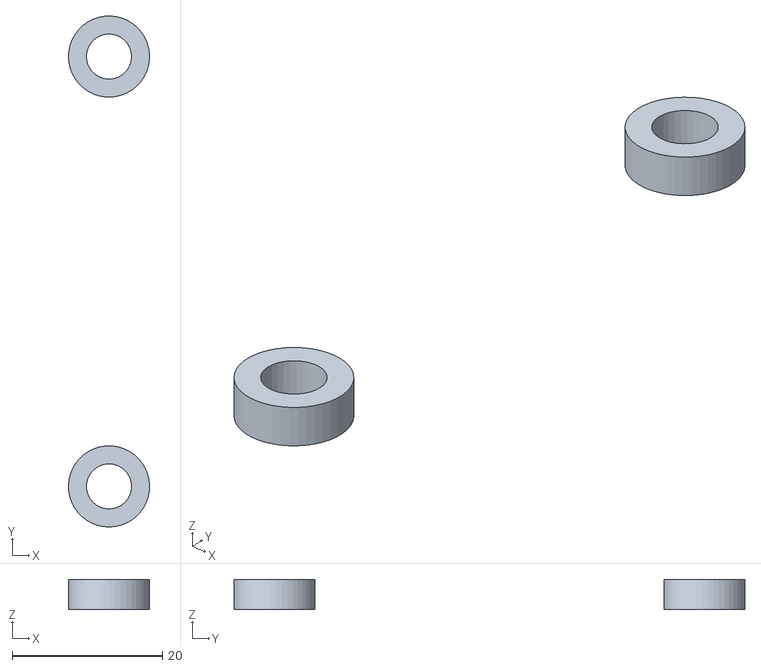
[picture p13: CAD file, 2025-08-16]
3D stl CAD filees/steering spacer 1.stl
10.8 x 68.0 x 4.00

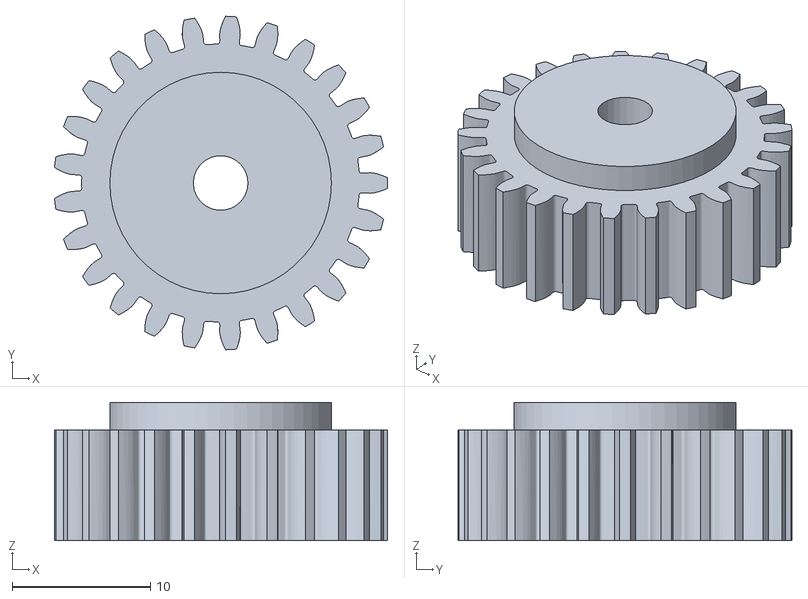
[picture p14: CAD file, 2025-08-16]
3D stl CAD filees/gear 5.stl
24.1 x 24.1 x 10.0

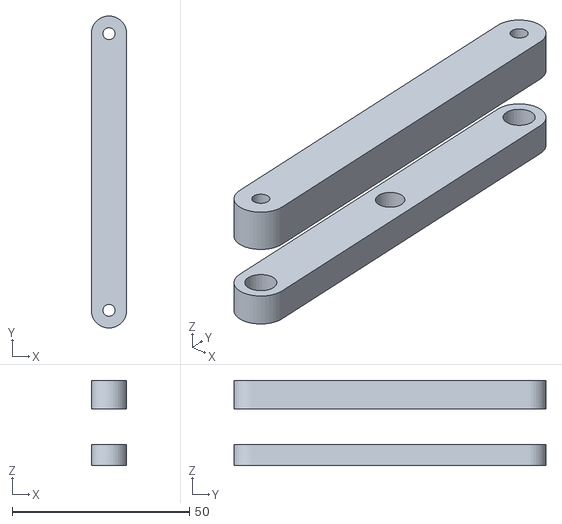
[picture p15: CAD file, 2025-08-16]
3D stl CAD filees/steering bar AB 1.stl
10.0 x 88.0 x 24.0

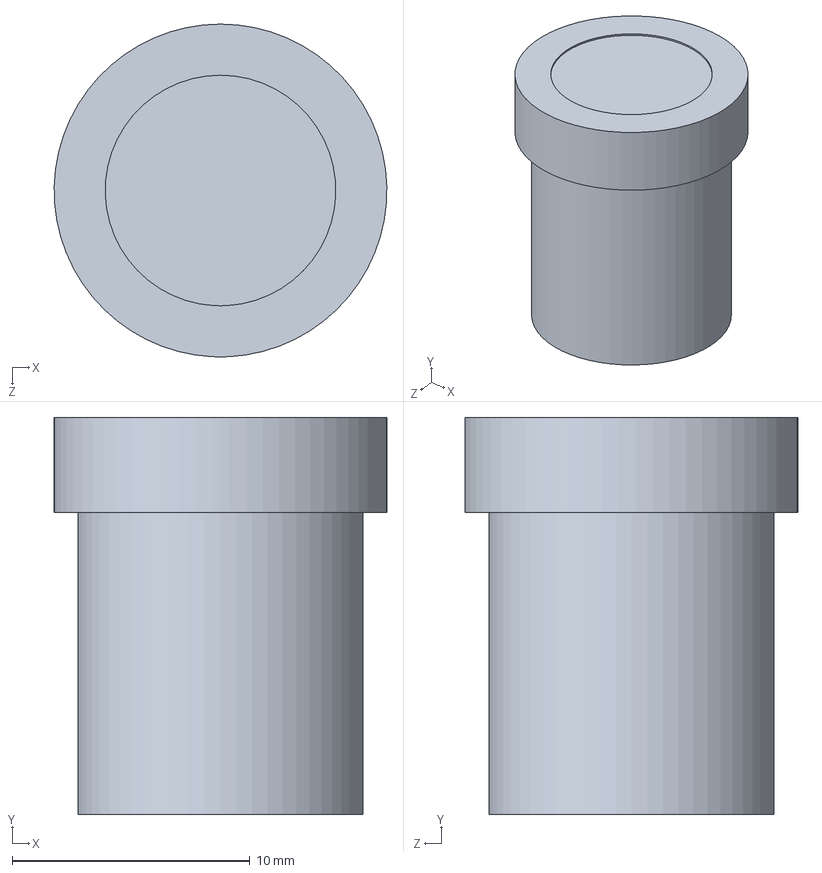
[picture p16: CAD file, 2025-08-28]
Open MV H7 model/LENS_Standard.SLDPRT
14.0 x 16.7 x 14.0 mm

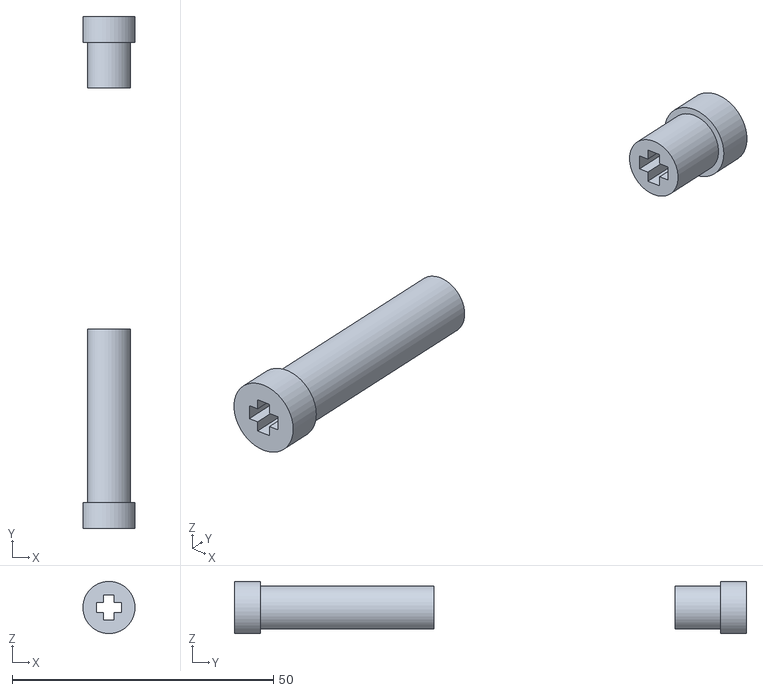
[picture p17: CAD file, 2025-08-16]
3D stl CAD filees/baring spacer 5.stl
9.99 x 98.0 x 9.99

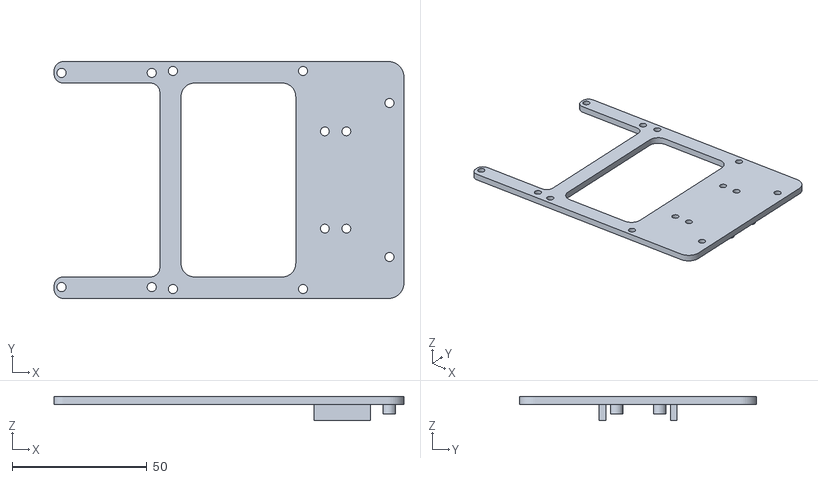
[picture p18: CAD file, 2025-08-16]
3D stl CAD filees/top plate 1.stl
130.0 x 88.0 x 9.00

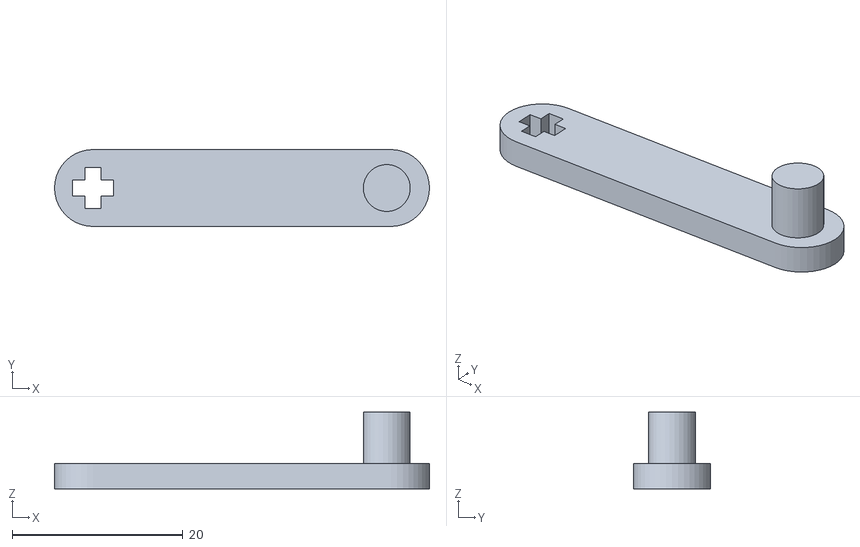
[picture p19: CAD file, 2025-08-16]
3D stl CAD filees/steering shaft 1.stl
43.9 x 9.00 x 9.00

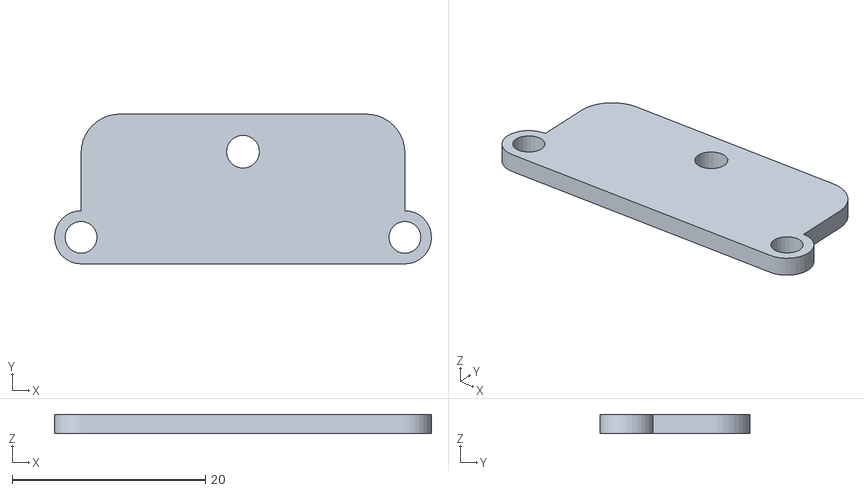
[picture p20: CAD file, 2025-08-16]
3D stl CAD filees/compass 1.stl
39.0 x 15.5 x 2.00

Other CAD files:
3D stl CAD filees/UNO plate 1.stl
3D stl CAD filees/switch box.stl
3D stl CAD filees/gear 3.stl
3D stl CAD filees/gear 4.stl
3D stl CAD filees/01 switch.stl
3D stl CAD filees/Drive Baring 1_.stl
3D stl CAD filees/Drive Baring 2.stl
3D stl CAD filees/Drive d.stl
3D stl CAD filees/Open plate 1.stl
3D stl CAD filees/STEERING BAR WITH SEN.stl
3D stl CAD filees/UNO plate 2.stl
3D stl CAD filees/baring spacer 1.stl
3D stl CAD filees/baring spacer 2.stl
3D stl CAD filees/baring spacer 3.stl
3D stl CAD filees/batt cov 1.stl
3D stl CAD filees/batt cov 2.stl
3D stl CAD filees/bno plate 1.stl
3D stl CAD filees/bottom plate 1.stl
3D stl CAD filees/cam module 1.stl
3D stl CAD filees/gear 1.stl
3D stl CAD filees/gear 2.stl
3D stl CAD filees/gear 6.stl
3D stl CAD filees/pole 7 special 1.stl
3D stl CAD filees/pole 7mm.stl
3D stl CAD filees/servo bracket 1.stl
3D stl CAD filees/servo bracket 2.stl
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

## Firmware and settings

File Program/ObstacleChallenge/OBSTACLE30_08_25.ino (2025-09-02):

#include "Mapf.h"
#include "Servo.h"

#include <Adafruit_Sensor.h>
#include <Adafruit_BNO055.h>
#include "CameraHandler.h"
#include <PID_v2.h>

#include <NeoSWSerial.h>

Adafruit_BNO055 bno = Adafruit_BNO055(55);

extern NeoSWSerial mySerial;

Servo myservo1;
Servo myservo2;

float pvYaw;
long open_timer;

#define RX_PIN 3  // Connect to OpenMV TX
#define TX_PIN 5  // Not used in this case, but define it if needed
NeoSWSerial mySerial(RX_PIN, TX_PIN);

BlobData blob;
BlobData purple_blob1;
BlobData purple_blob2;

//  Compass Variables

float yawOffset = 0;  // Stores the zero reference


const int buzzerPin = 4;

//  Motor B
// const int E1Pin = 10;
// const int M1Pin = 11;
// const int E2Pin = 12;
// const int M2Pin = 13;

const int ENA = 11;  // Motor A speed control (PWM)
const int IN1 = 12;  // Motor A direction 1
const int IN2 = 13;  // Motor A direction 2

/**inner definition**/
typedef struct {
  byte enPin;
  byte directionPin;
} MotorContrl;

const int M1 = 0;
const int MotorNum = 1;

// const MotorContrl MotorPin[] = { { E1Pin, M1Pin }, { E2Pin, M2Pin } };

const int Forward = LOW;
const int Backward = HIGH;

//  Servos
int const STEER_SRV = 9;
int const ULTRA_SRV = 8;

//  Ultrasonic Sensor
int const ULTRA_PIN = A3;

//  Light Sensors
int const RED_SEN = A1;
int const GEEN_SEN = A2;

//  Button
int const BUTTON = A0;

char TURN = 'U';
int compass_offset = 0;
long halt_detect_line_timer;
bool found_block = false;
int lines_detect_num = 0;
int Servo_Value;

//  Field Config
char Blocks_TURN = 'U';
float avoidance_degree = 0;
long timer_block_decay;
float found_block_factor;
int x = -1;
int Y = 30;
int count = 0;
int realCount = 0;

CameraHandler camera;
// Specify the links and initial tuning parameters
PID_v2 compassPID(0.6, 0.0001, 0.02, PID::Direct);

void setup() {
  compassPID.Start(0, 0, 0);
  compassPID.SetOutputLimits(-180, 180);
  compassPID.SetSampleTime(10);
  pinMode(ENA, OUTPUT);
  pinMode(IN1, OUTPUT);
  pinMode(IN2, OUTPUT);
  pinMode(buzzerPin, OUTPUT);

  pinMode(STEER_SRV, OUTPUT);
  pinMode(ULTRA_SRV, OUTPUT);
  pinMode(ULTRA_PIN, INPUT);
  pinMode(RED_SEN, INPUT);
  pinMode(GEEN_SEN, INPUT);
  pinMode(BUTTON, INPUT);
  Serial.begin(9600);
  mySerial.begin(19200);
  // initMotor();
  // pixy.changeProg("color_connected_components");
  // while (!Serial)
  //   ;
  BNOset();
  myservo1.attach(ULTRA_SRV, 600, 2500);
  myservo2.attach(STEER_SRV, 600, 2400);
  steering_servo(0);
  ultra_servo(0, 'L');
  // check_leds();
  // while (true) {
  // getIMU();
  // Serial.print("Compass : ");
  // Serial.println(pvYaw);
  // }
  // myservo1.write(50);
  // delay(100000);
  zeroYaw();
  simpleBeep();
  while (analogRead(BUTTON) > 500)
    ;
  simpleBeep();

  while (analogRead(BUTTON) <= 500)
    ;
  delay(600);
}

void loop() {
  long countdown_stop = millis();

  while (analogRead(BUTTON) > 500) {
    camera.handleIncomingData();
    getBNO();
    line_detection();
    int distance_wall = getDistance();

    // Use TURN (not Blocks_TURN) for consistency
    int steering_degree = (1 * x) * compassPID.Run((x * pvYaw) + ((distance_wall - Y)) * ((float(Blocks_TURN == 'TURN') - 0.5) * 2)) * -1;

    if (millis() - open_timer > 50) {
      avoidance_degree = calculate_avoidance();
      open_timer = millis();
    }

    int final_degree = map(max(found_block, found_block_factor), 0, 1, steering_degree, mapf(min(max(distance_wall, 5), 40), 5, 40, steering_degree, avoidance_degree * 2.5));

    if (count >= 1) {

      long timer01 = millis();
      while (millis() - timer01 < 4000) {
        camera.handleIncomingData();
        getBNO();
        // line_detection();
        int distance_wall = getDistance();

        // Use TURN (not Blocks_TURN) for consistency
        int steering_degree = (1 * x) * compassPID.Run((x * pvYaw) + ((distance_wall - Y)) * ((float(Blocks_TURN == 'TURN') - 0.5) * 2)) * -1;

        if (millis() - open_timer > 50) {
          avoidance_degree = calculate_avoidance();
          open_timer = millis();
        }

        int final_degree = map(max(found_block, found_block_factor), 0, 1, steering_degree, mapf(min(max(distance_wall, 5), 40), 5, 40, steering_degree, avoidance_degree * 2.5));
        //   getBNO();
        //   line_detection();
        //   motor_and_steer((1 * x) * compassPID.Run((x * pvYaw) + ((distance_wall - Y)) * ((float(TURN == 'TURN') - 0.5) * 2)) * -1);
        //   ultra_servo(-pvYaw, TURN);  // Use TURN here too
        ultra_servo(-pvYaw, Blocks_TURN);
        motor_and_steer(final_degree);
      }
      count = 0;
      realCount++;
      // break;
    }

    if (realCount >= 1) {
    setMotorPercent(0);
    simpleBeep();
    while (true) {
    }
    // Use TURN for servo direction (this should match the robot's movement direction)
  }


    ultra_servo(-pvYaw, Blocks_TURN);
    motor_and_steer(final_degree);
  }

  setMotorPercent(0);
  while (analogRead(BUTTON) <= 500)
    ;
  while (analogRead(BUTTON) > 500)
    ;
  while (analogRead(BUTTON) <= 500)
    ;
}

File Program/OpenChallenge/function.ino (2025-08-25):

void BNOset() {
  Serial.println("Initializing BNO055...");
  if (!bno.begin()) {
    Serial.println("Ooops, no BNO055 detected ... Check your wiring or I2C ADDR!");
    while (1) {
      digitalWrite(buzzerPin, HIGH);
      delay(100);
      digitalWrite(buzzerPin, LOW);
      delay(100);
    }
  }

  delay(1000);  // Give the sensor some time to initialize
  bno.setExtCrystalUse(true);
  Serial.println("BNO055 initialized successfully!");
}

/* Read BNO055 and compute relative yaw */
bool getBNO() {
  sensors_event_t event;
  bno.getEvent(&event);

  // Wrap raw yaw to -180 ~ 180
  float yaw = wrap_value(event.orientation.x, -179.0, 180.0);

  // Compute relative yaw using the offset
  pvYaw = yaw;
  pvYaw = wrap_value(pvYaw + compass_offset + min(max(mapf(getDistance(), 10, 25, 0, 1), 0), 1) * mapf(min(millis() - halt_detect_line_timer, 1000), 0, 1000, 25, 0) * (compass_offset >= 0 - 0.5) * 2, -179, 180);
}




int wrapValue(int value, int minValue, int maxValue) {
  int range = maxValue - minValue + 1;
  if (value < minValue) {
    value += range * ((minValue - value) / range + 1);
  }
  return minValue + (value - minValue) % range;
}

float getDistance() {
  return min(mapf(analogRead(ULTRA_PIN), 0, 1023, 0, 500), 50);
}


void ultra_servo(int degree, char mode_steer) {
  int middle_degree = 0;
  if (mode_steer == 'F') {
    middle_degree = 270;
  } else if (mode_steer == 'R') {
    middle_degree = 360;
  } else if (mode_steer == 'L' || mode_steer == 'U') {
    middle_degree = 180;
  } else {
    // beep();
  }
  Servo_Value = ((max(min(middle_degree + degree, 360), 180)) / 2);
  myservo1.write(Servo_Value);
  // myservo1.write(mapf(max(min(middle_degree + degree, 225), 45), 0, 270, 0, 180));
}

void steering_servo(int degree) {
  myservo2.write(mapf(135 + max(min(degree, 25), -25), 0, 270, 0, 180));
}

void motor_and_steer(int degree) {
  degree = max(min(degree, 35), -35);
  steering_servo(degree);
  setMotorPercent(map(abs(degree), 0, 45, 70, 70));
  // setMotorSpeed2(-100);
}

// void beep() {
//   digitalWrite(BUZZER, HIGH);
//   delay(100);
//   digitalWrite(BUZZER, LOW);
// }

void line_detection() {
  int GEEN_value = analogRead(GEEN_SEN);

  found_block_factor = min(max(mapf(millis() - timer_block_decay, 0, 1000, 1, 0), 0), 1);

  if (TURN == 'U') {
    int red_value = analogRead(RED_SEN);
    if (GEEN_value < 400 || red_value < 500) {
      int lowest_red_sen = red_value;
      long timer_line = millis();
      while (millis() - timer_line < 100) {
        int red_value = analogRead(RED_SEN);
        if (red_value < lowest_red_sen) {
          lowest_red_sen = red_value;
        }
      }
      if (lowest_red_sen > 500) {
        // Red
        TURN = 'L';
        Blocks_TURN = 'R';
        compass_offset -= 90;
        x = -1;
        Y = 16;
        // beep();
      } else {
        // Blue
        TURN = 'R';
        Blocks_TURN = 'L';
        compass_offset += 90;
        x = 1;
        Y = 28;
        // beep();
        // delay(100);
        // beep();
        // delay(100);
        // beep();
      }
      count++;
      halt_detect_line_timer = millis();
    }
  } else {
    if (millis() - halt_detect_line_timer > 800) {
      if (found_block) {
        timer_block_decay = millis();
      }
      if (GEEN_value < 400) {
        if (TURN == 'L') {
          TURN = 'L';
          x = -1;
          compass_offset -= 90;
        } else {
          TURN = 'R';
          compass_offset += 90;
          x = +1;
        }
        halt_detect_line_timer = millis();
        count++;
      }
    }
  }
}

void simpleBeep() {
  digitalWrite(buzzerPin, HIGH);
  delay(100);
  digitalWrite(buzzerPin, LOW);
}

// void initMotor() {
//   int i;
//   for (i = 0; i < MotorNum; i++) {
//     digitalWrite(MotorPin[i].enPin, LOW);

//     pinMode(MotorPin[i].enPin, OUTPUT);
//     pinMode(MotorPin[i].directionPin, OUTPUT);
//   }
// }

// /**  motorNumber: M1, M2
// direction:          Forward, Backward **/
// void setMotorDirection(int motorNumber, int direction) {
//   digitalWrite(MotorPin[motorNumber].directionPin, direction);
// }

// /** speed:  0-100   * */
// inline void setMotorSpeed(int motorNumber, int speed) {
//   analogWrite(MotorPin[motorNumber].enPin, (int)(255.0 * ((float)speed / 100.0)));
// }

void zeroYaw() {
  sensors_event_t event;
  bno.getEvent(&event);
  float yawOffset = wrap_value(event.orientation.x, -180.0, 180.0);
}

// float yawOffset = constrain(event.orientation.x, -180.0, 180.0);
// Serial.print("Yaw offset set to: ");
// Serial.println(yawOffset);

float wrap_value(float value, float min_value, float max_value) {
  float range_val = max_value - min_value;
  while (value < min_value) value += range_val;
  while (value > max_value) value -= range_val;
  return value;
}



void check_leds() {
  while (true) {
    Serial.print("Geen: ");
    Serial.print(analogRead(GEEN_SEN));
    Serial.print("   Red: ");
    Serial.println(analogRead(RED_SEN));
    line_detection();
  }
}

void check_BUTTON() {
  while (true) {
    Serial.print("Button: ");
    Serial.println(analogRead(BUTTON));
  }
}

/*
  Motor control with speed scale -100 to +100
  Arduino Motor Shield R3 (L293D)
  Motor A: PWM on pin 3, direction on pins 12 & 13
*/



// Function to set motor speed (-100 to +100)
// void setMotorSpeed2(int speedPercent) {
//   speedPercent = constrain(speedPercent, -100, 100);  // clamp range

//   if (speedPercent > 0) {
//     // Forward
//     digitalWrite(motorDirPin1, HIGH);
//     digitalWrite(motorDirPin2, LOW);
//     analogWrite(motorSpeedPin, map(speedPercent, 0, 100, 0, 255));
//   } else if (speedPercent < 0) {
//     // Reverse
//     digitalWrite(motorDirPin1, LOW);
//     digitalWrite(motorDirPin2, HIGH);
//     analogWrite(motorSpeedPin, map(-speedPercent, 0, 100, 0, 255));
//   } else {
//     // Stop (brake)
//     digitalWrite(motorDirPin1, LOW);
//     digitalWrite(motorDirPin2, LOW);
//     analogWrite(motorSpeedPin, 0);
//   }
// }

void setMotorPercent(int sp) {
  sp = constrain(sp, -100, 100);

  if (sp > 0) {
    digitalWrite(IN1, HIGH);
    digitalWrite(IN2, LOW);
    analogWrite(ENA, map(sp, 0, 100, 0, 255));
  } else if (sp < 0) {
    digitalWrite(IN1, LOW);
    digitalWrite(IN2, HIGH);
    analogWrite(ENA, map(-sp, 0, 100, 0, 255));
  } else {
    // brake (both low) OR set both high for hard brake on some boards
    digitalWrite(IN1, LOW);
    digitalWrite(IN2, LOW);
    analogWrite(ENA, 0);
  }
}


// float calculate_avoidance() {
//   int blocks = pixy.ccc.getBlocks();


//     found_block = false;

//   if (blocks) {
//     int signature = -1;       // Signature of the object you want to detect
//     int targetHeight = 10;    // Height of the object in centimeters
//     float focalLength = 2.3;  // Focal length of the camera in centimeters
//     float cameraFOV = 80.0;   // Field of view of the camera in degrees

//     int largestBlockIndex = -1;
//     int largestBlockArea = 0;
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

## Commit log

2025-08-28 Open MV H7 model
    [LENS_Standard.SLDPRT, LENS_Wide.SLDPRT, openmv4_h7.SLDASM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]
2025-09-01 Create Circuit
